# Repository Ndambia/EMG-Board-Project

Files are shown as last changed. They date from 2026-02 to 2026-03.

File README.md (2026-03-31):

# 3-Channel EMG Data Acquisition System (ESP32-Based)

## Overview

This project is a **3-channel Electromyography (EMG) Data Acquisition (DAQ) system** built around an **ESP32 MCU**. It is designed to acquire low-level biopotential signals from muscles, condition them using an analog front-end, digitize them via an external ADC, and transmit or store the data for further processing.

The system is modular and portable, integrating power management for battery operation, making it suitable for wearable and embedded biomedical applications.

---

## Key Features

* Three independent EMG input channels
* External multi-channel ADC with I²C interface
* ESP32 MCU for control, DSP, and communication
* Li-Po battery charging support
* Boost / regulation circuitry for stable operation
* Compact PCB designed for embedded and wearable use

---

## System Architecture

### Signal Chain Overview

```
Muscle Electrodes
      ↓
EMG Analog Front-End (DAQ)
      ↓
External ADC (3 Channels)
      ↓  I²C
ESP32 MCU
      ↓
USB / BLE / Wi-Fi 
```

---

## Functional Block Description

### 1. EMG DAQ (Analog Front-End)

* Three independent EMG channels
* Powered at **3.3 V**
* Outputs conditioned analog signals suitable for ADC input

**Typical functionality includes:**

* Instrumentation amplification
* High-pass filtering to remove motion artifacts
* Low-pass filtering to reduce high-frequency noise
* Optional 50/60 Hz notch filtering

---

### 2. Analog-to-Digital Converter (ADC)

* Powered at **3.3 V**
* Three analog input channels
* Digital interface: **I²C (SDA, SCL)**

The ADC digitizes the conditioned EMG signals for processing by the ESP32.

---

### 3. Microcontroller Unit (ESP32)

* Powered at **3.3 V**
* Configures and reads data from the ADC
* Performs optional digital signal processing (RMS, envelope extraction)
* Supports USB, BLE, and Wi-Fi communication

---

### 4. Power Management

#### Li-Po Battery Charger

* Supports single-cell Li-Po batteries
* USB-powered charging
* Enables portable operation

#### Boost / Regulation Circuit

* Maintains stable system voltage during battery discharge
* Ensures reliable operation of analog and digital blocks

---

## PCB Design

### PCB Back Layer

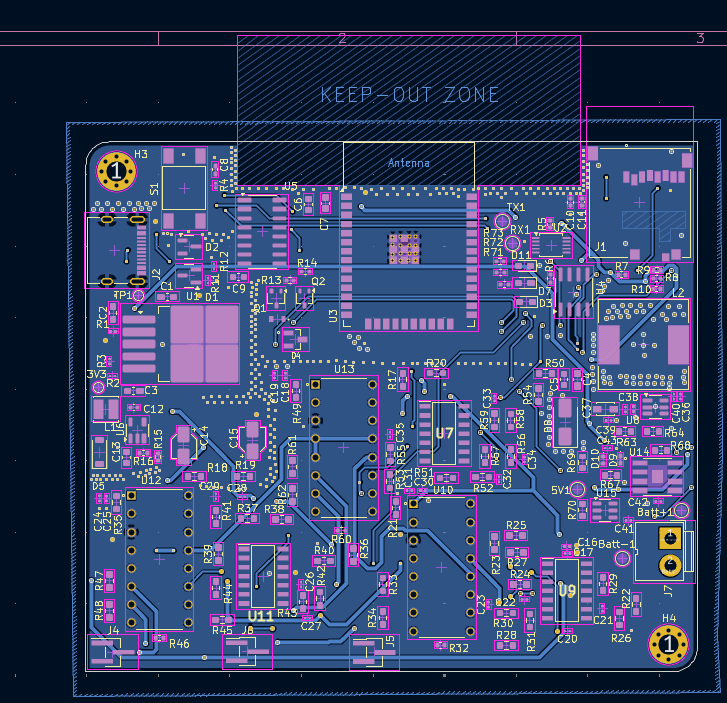
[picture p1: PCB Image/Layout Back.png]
PCB Back

The back layer shows the ground plane distribution and return paths. Care was taken to maintain a low-impedance ground for the analog EMG front-end to minimize noise coupling from digital sections.

### PCB Front Layer

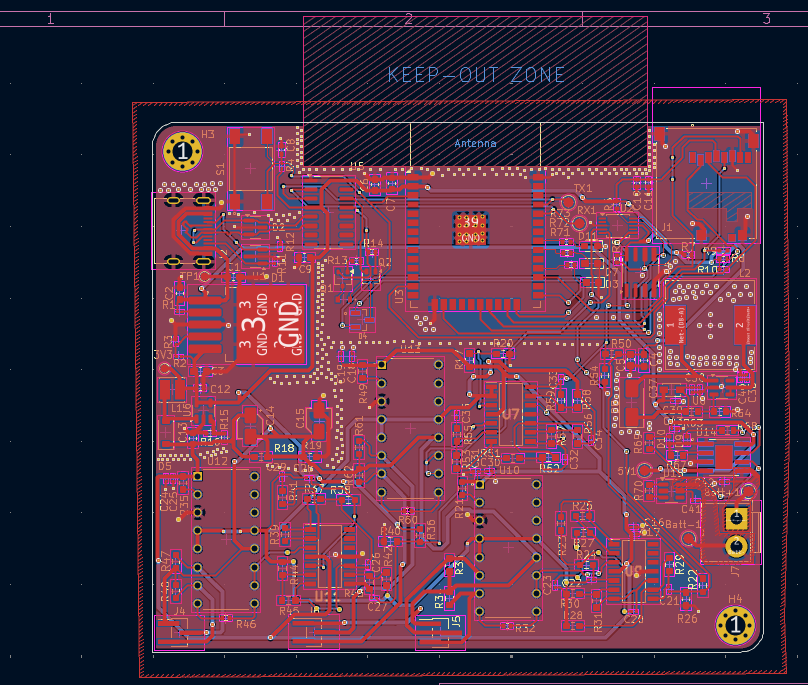
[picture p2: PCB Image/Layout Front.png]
PCB Front

The front layer contains the majority of signal routing and component placement. Analog EMG paths are kept short and isolated from high-speed digital and power traces.

### PCB Routing Overview

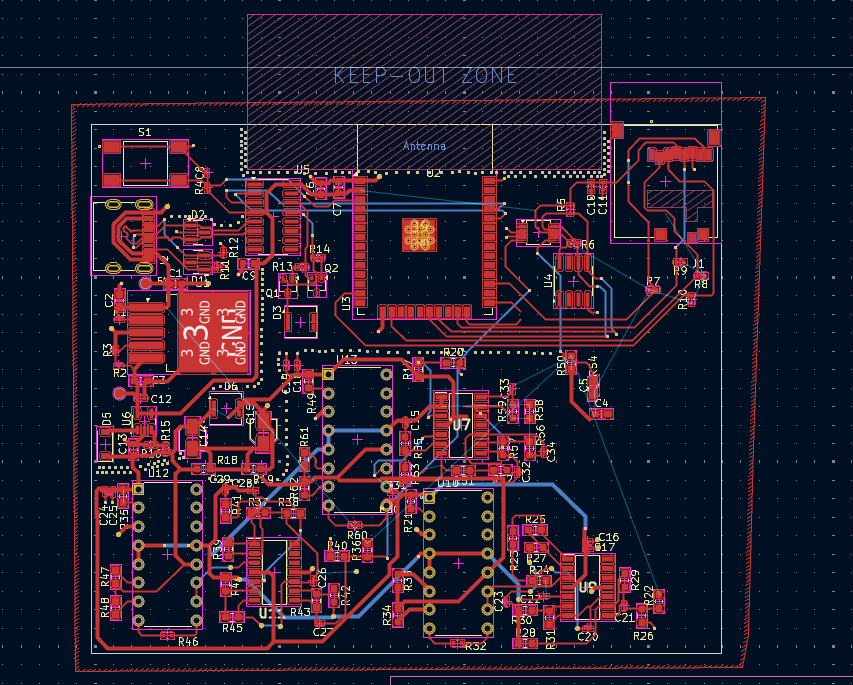
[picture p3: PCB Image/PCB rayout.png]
PCB Layout

This image provides an overall routing overview, highlighting trace organization, separation between analog and digital domains, and controlled routing for sensitive EMG signals.

### Routing – Front

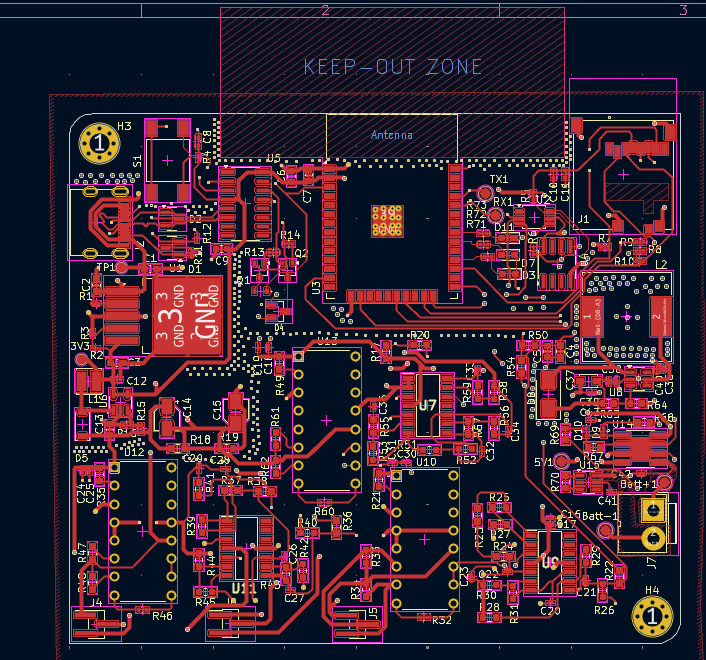
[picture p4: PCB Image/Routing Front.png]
Routing Front

The front routing layer illustrates how EMG signal traces are carefully routed with minimal vias to reduce interference and preserve signal integrity.

### Routing – Back

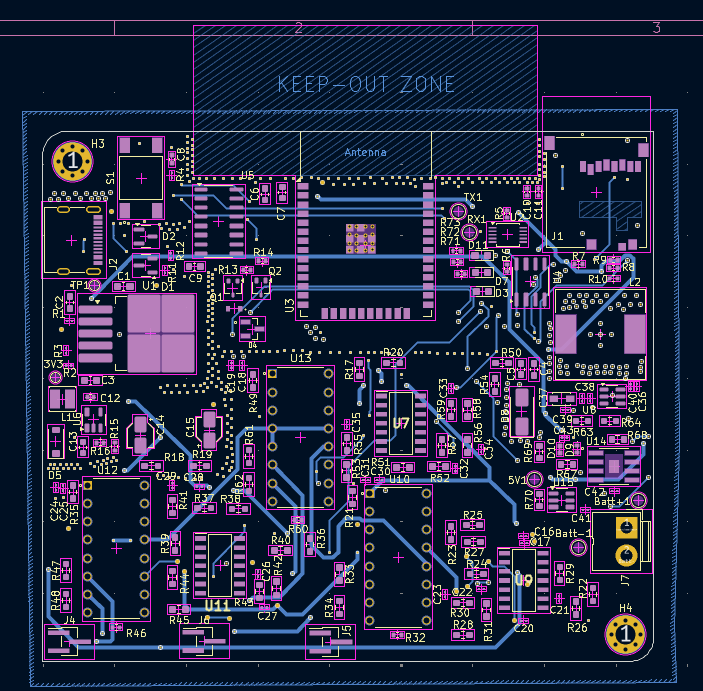
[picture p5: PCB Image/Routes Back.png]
Routing Back

Back-side routing is primarily used for ground returns and power distribution, helping to maintain clean reference planes for low-noise acquisition.

### PCB 3D View

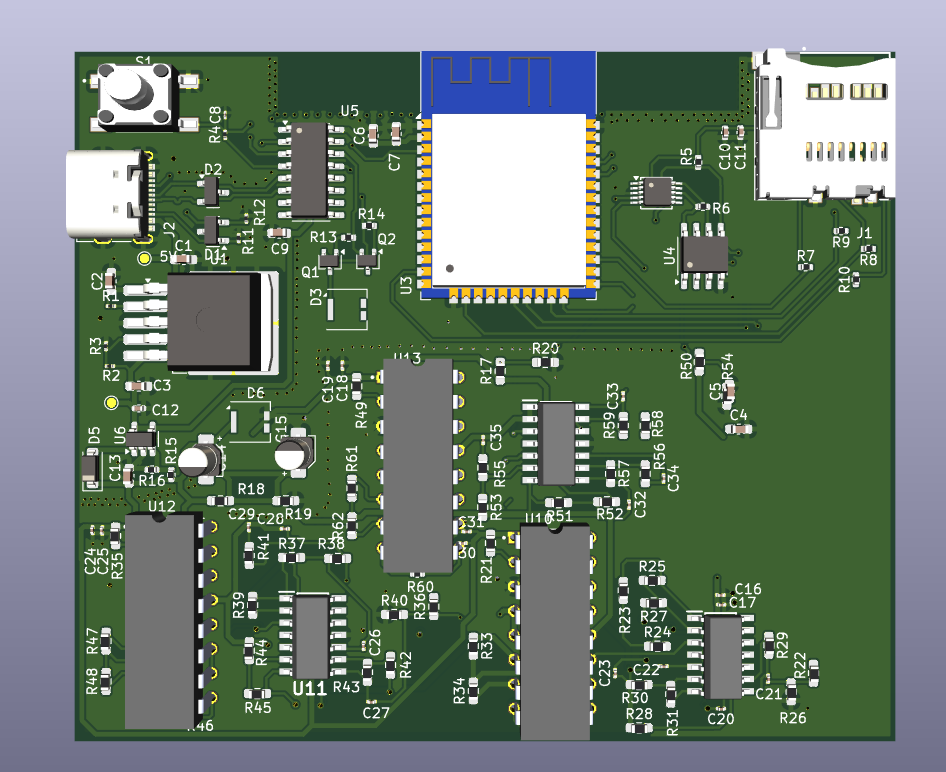
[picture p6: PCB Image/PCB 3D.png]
PCB 3D

The 3D view shows overall board dimensions, component height clearance, and suitability for enclosure or wearable integration.

### PCB Front 3D View

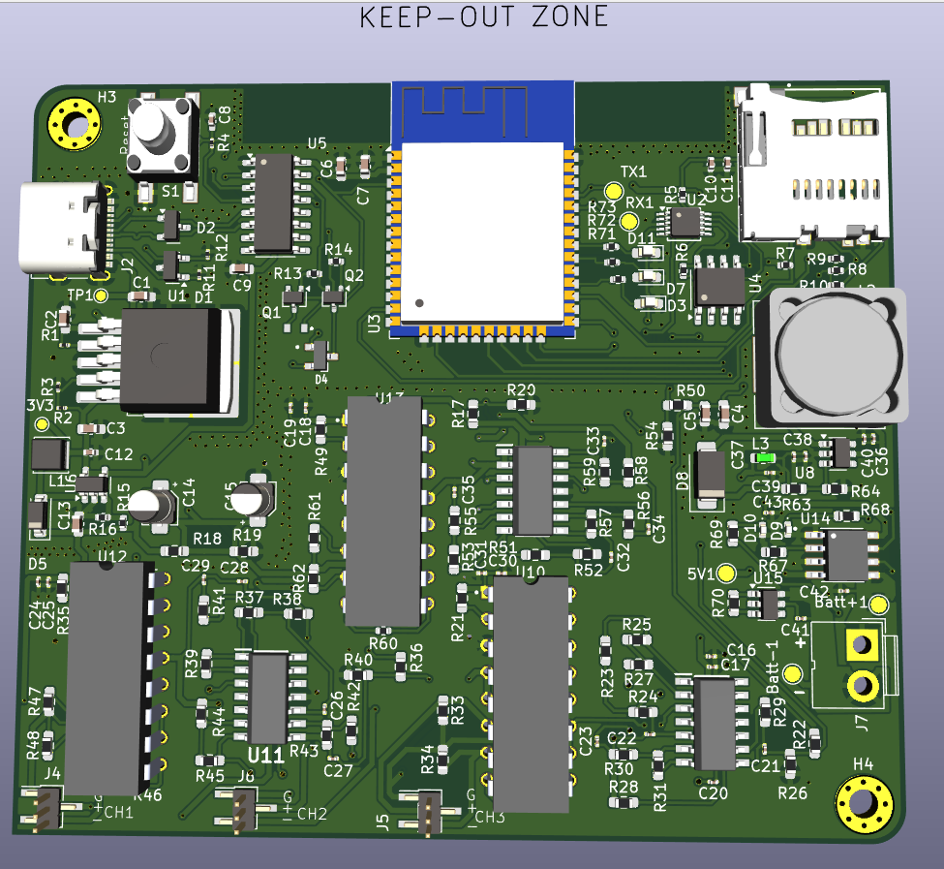
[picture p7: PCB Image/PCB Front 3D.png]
PCB Front 3D

This view highlights top-side component placement, including the ESP32 module, ADC, and EMG front-end circuitry.

### PCB Back 3D View

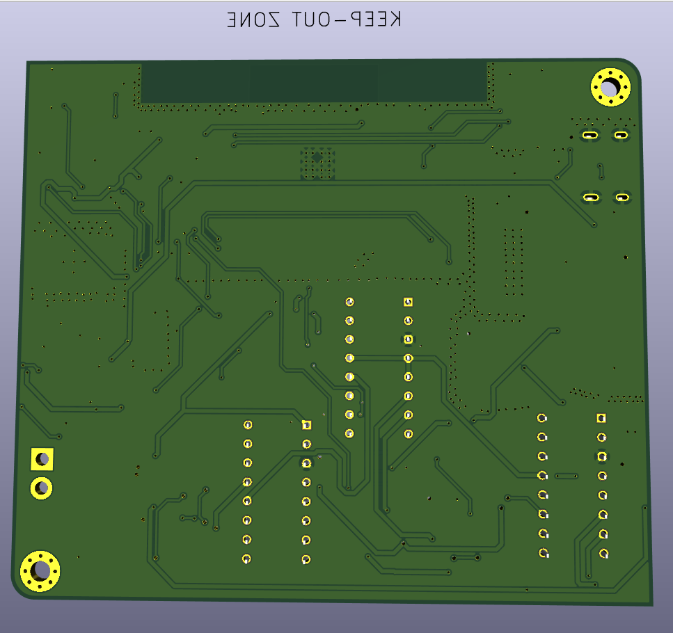
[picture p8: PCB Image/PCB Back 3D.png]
PCB Back 3D

The back-side 3D view shows passive components, ground stitching vias, and mechanical layout considerations.

### Design Progress Snapshot

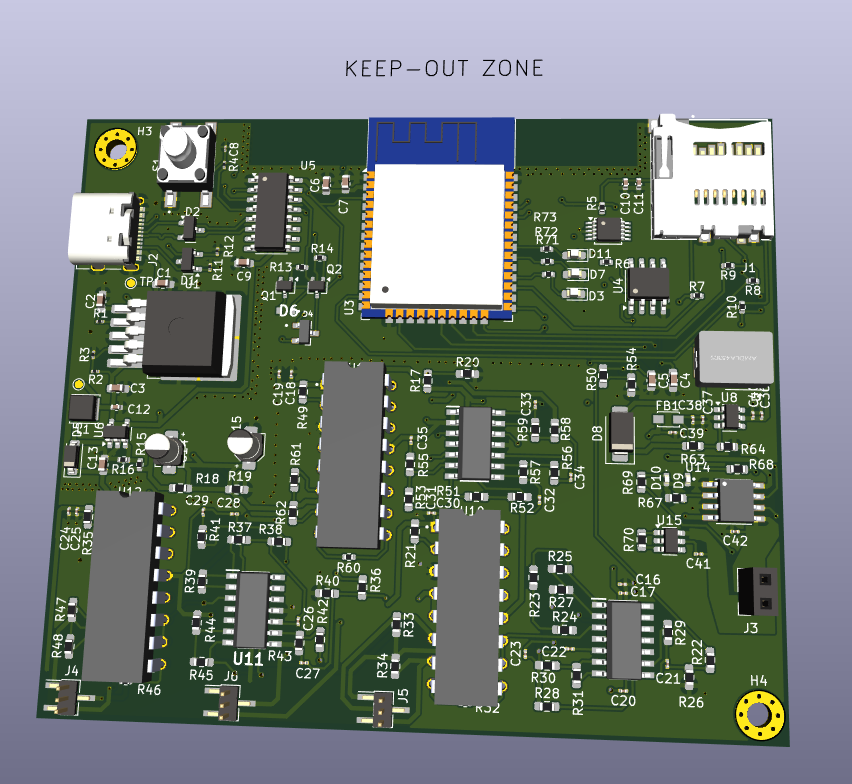
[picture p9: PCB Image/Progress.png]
Progress

This image documents the PCB design progress during layout and routing stages.

### Schematics

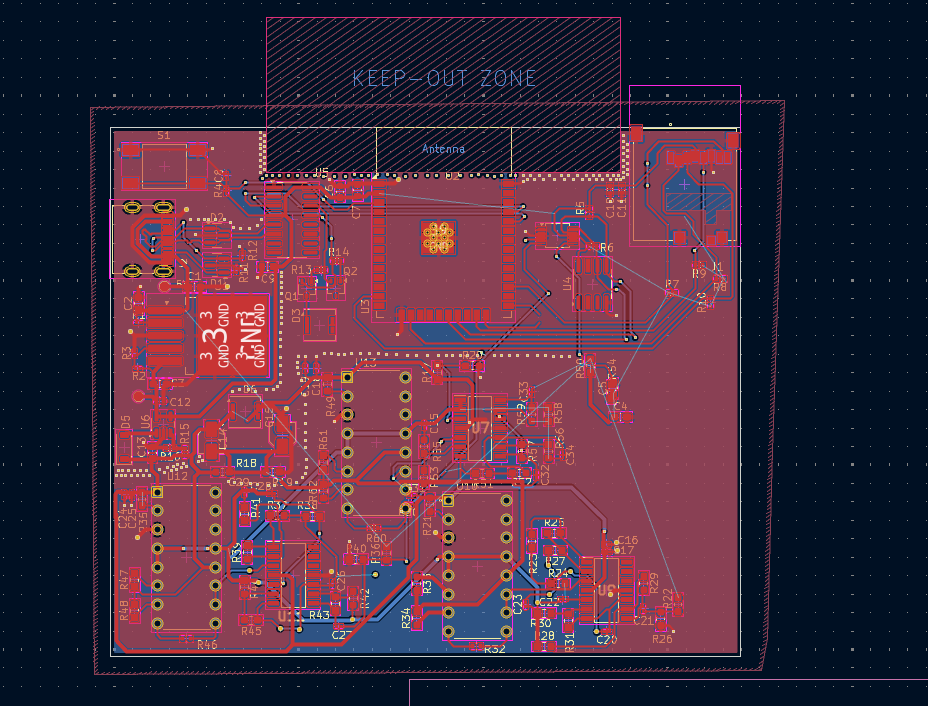
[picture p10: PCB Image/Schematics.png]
Schematics

The schematic captures the complete system design, including EMG analog front-end, ADC, ESP32 MCU, and power management circuitry.

---

## Intended Applications

* Multi-channel EMG signal acquisition
* Wearable biomedical research devices
* Prosthetics and rehabilitation research
* Gesture recognition and HMI systems
* Academic and laboratory EMG experimentation

---

## Design Notes & Safety

* Proper analog grounding and shielding are critical for low-noise EMG acquisition
* Use shielded electrode cables where possible
* This system is intended for **research and educational use only**
* Not certified for clinical or diagnostic applications

---

## Author

**Eng. Ndambia M.**
MyGen Solutions

---

## License & Disclaimer

This project is provided for **research and educational purposes only**. It is not a certified medical device and must not be used for clinical diagnosis or treatment.

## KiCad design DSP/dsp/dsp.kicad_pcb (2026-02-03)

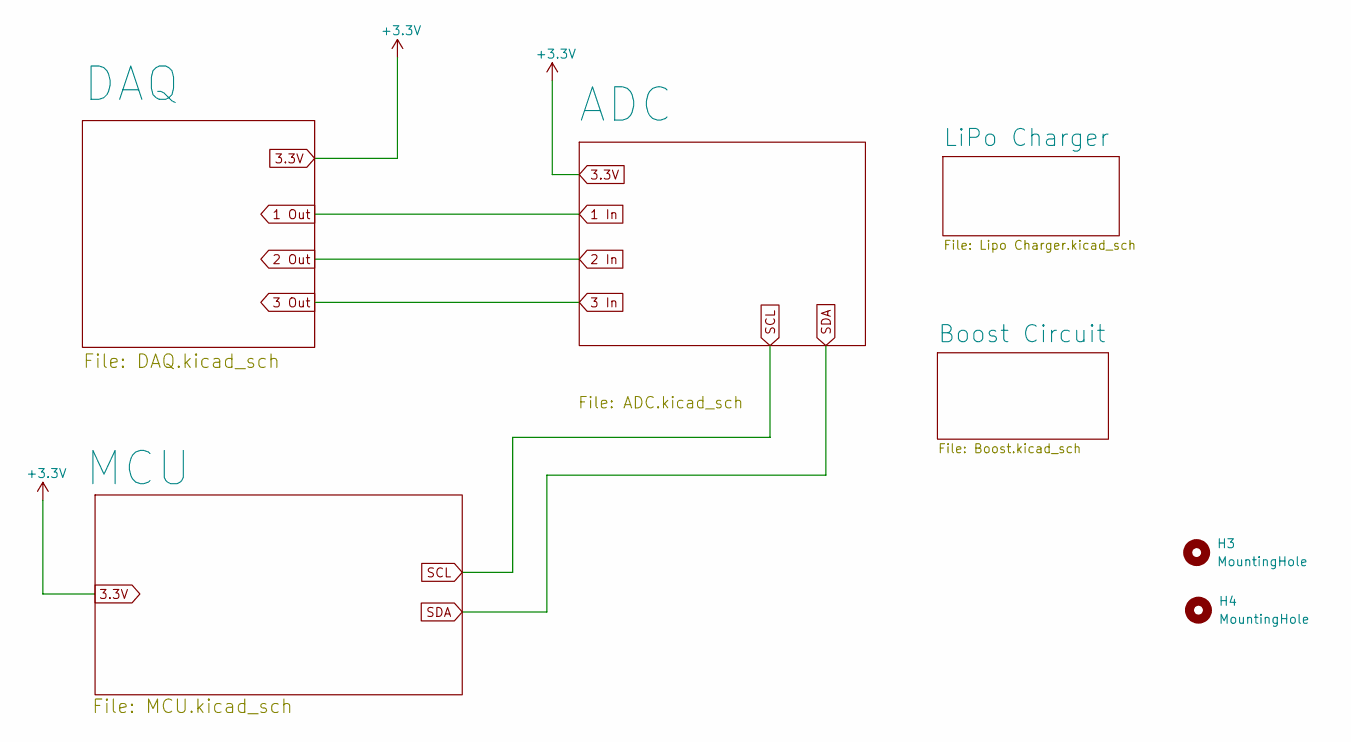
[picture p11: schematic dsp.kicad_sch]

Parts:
H3, H4: MountingHole; MountingHole_2.7mm_M2.5_Pad_Via

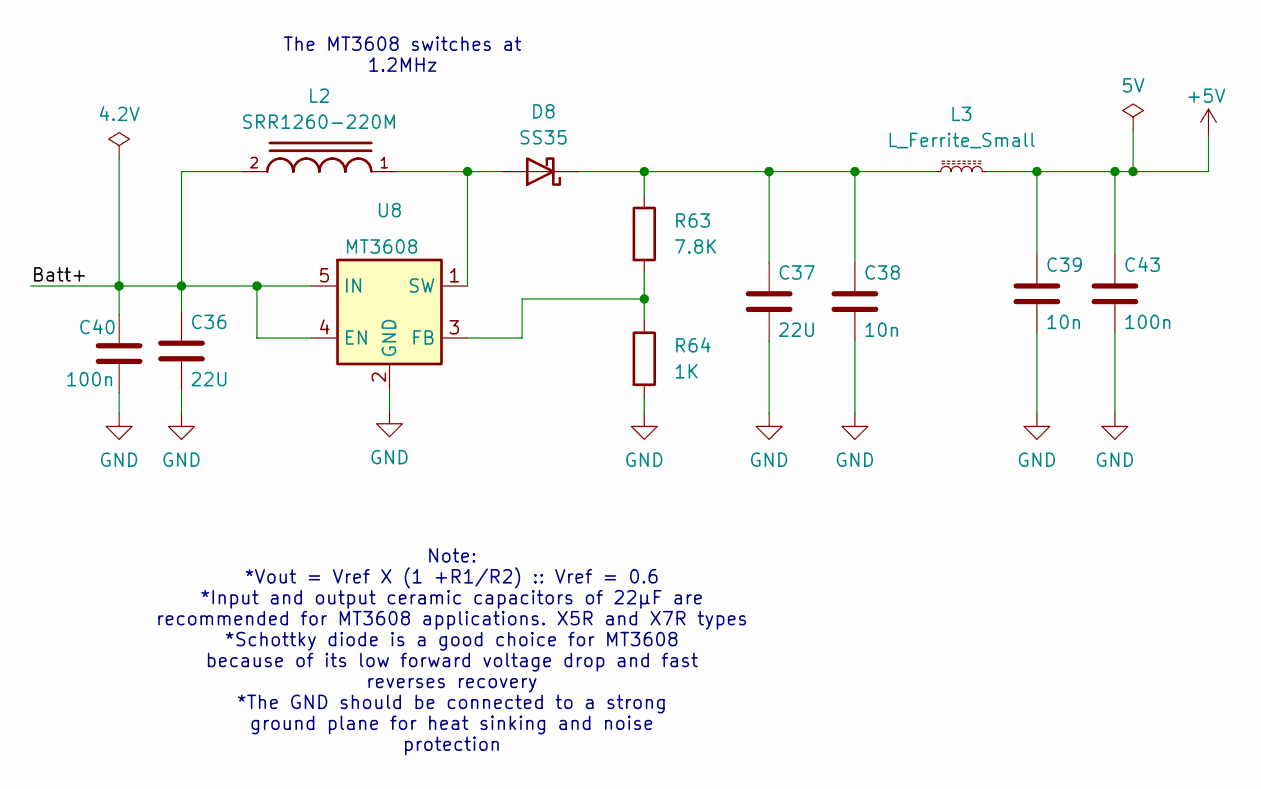
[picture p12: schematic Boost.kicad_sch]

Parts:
C36, C37: 22U; C_0201_0603Metric
C38, C39: 10n; C_0201_0603Metric
C40, C43: 100n; C_0201_0603Metric
D8: SS35; D_SMA
L2: SRR1260-220M; INDP125125X600N
L3: L_Ferrite_Small; L_0603_1608Metric
R63: 7.8K; R_0603_1608Metric
R64: 1K; R_0603_1608Metric
U8: MT3608; SOT-23-6

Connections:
5V: C39.1, C43.1, L3.2; also elsewhere on the board
/Boost Circuit/Batt+: C36.1, C40.1, L2.2, U8.4 (EN), U8.5 (IN)
GND: C36.2, C37.2, C38.2, C39.2, C40.2, C43.2, R64.2, U8.2 (GND); also elsewhere on the board
unnamed: D8.2 (A), L2.1, U8.1 (SW)
unnamed: C37.1, C38.1, D8.1 (K), L3.1, R63.1
unnamed: R63.2, R64.1, U8.3 (FB)

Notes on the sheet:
Note: *Vout = Vref X (1 +R1/R2) :: Vref = 0.6 *Input and output ceramic capacitors of 22μF are recommended for MT3608 applications. X5R and X7R types *Schottky diode is a good choice for MT3608 because of its low forward voltage drop and fast reverses recovery *The GND should be connected to a stro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
The MT3608 switches at 1.2MHz

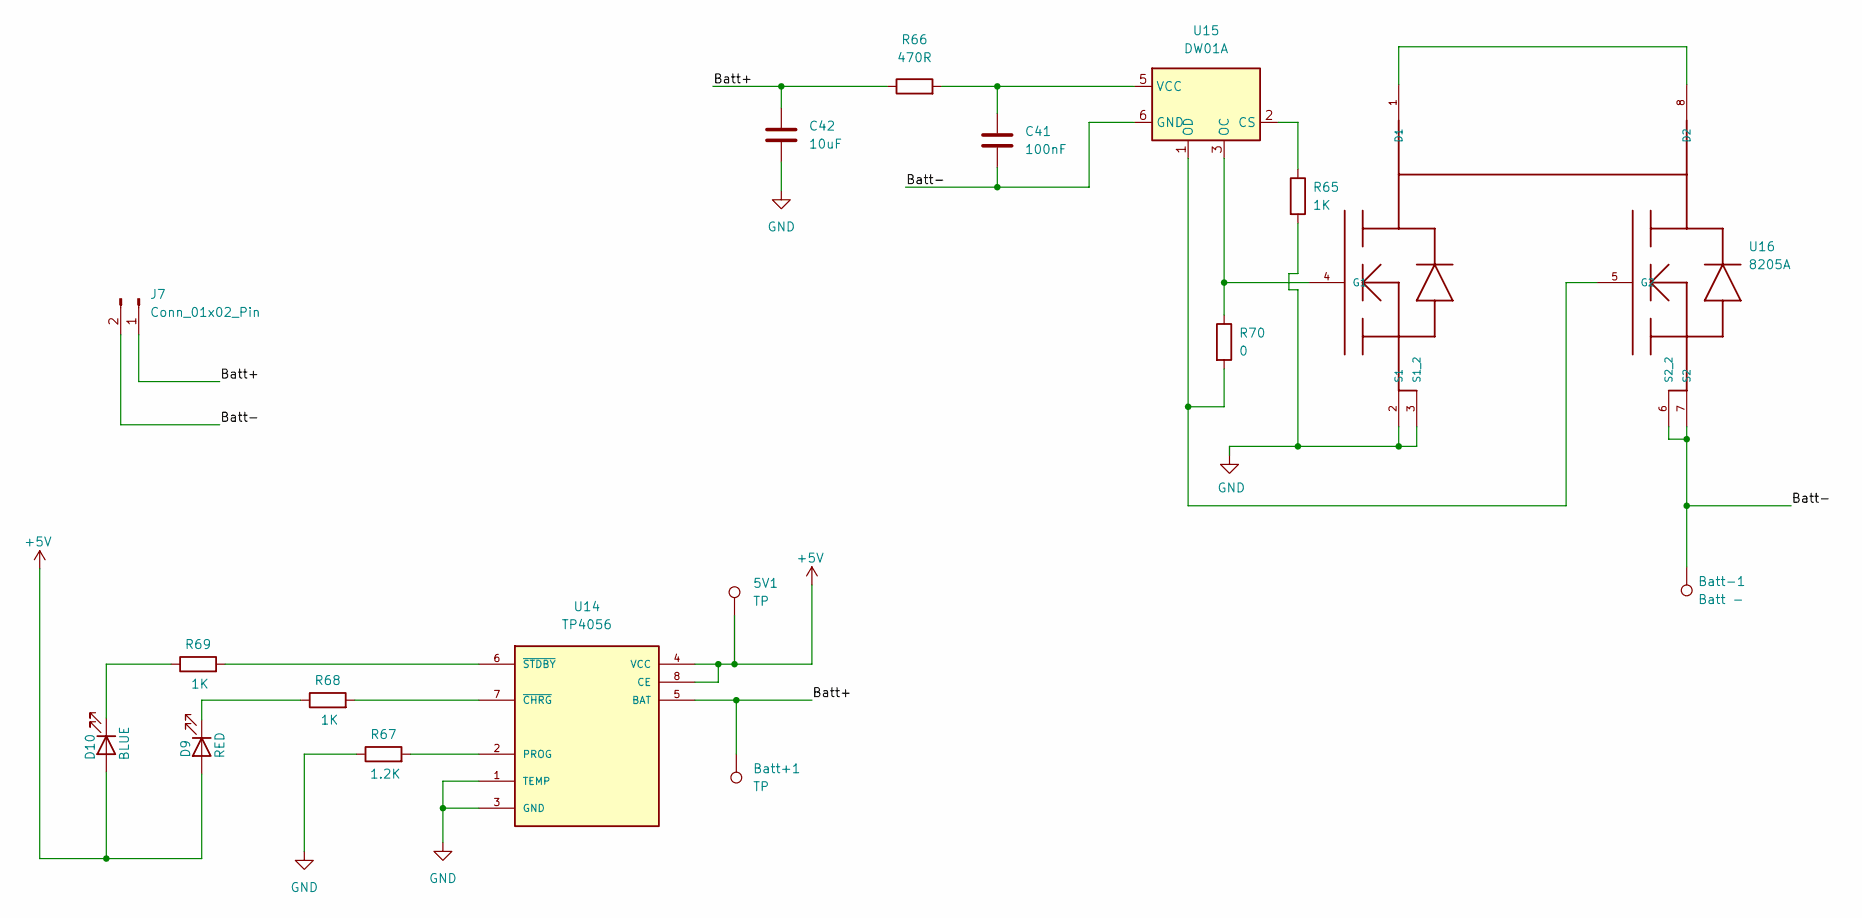
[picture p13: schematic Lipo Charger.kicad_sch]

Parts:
5V1: TP; TestPoint_Pad_D1.5mm
Batt+1: TP; TestPoint_Pad_D1.5mm
Batt-1: Batt -; TestPoint_Pad_D1.5mm
C41: 100nF; C_0201_0603Metric
C42: 10uF; C_0201_0603Metric
D9: RED; LED_0402_1005Metric
D10: BLUE; LED_0402_1005Metric
J7: Conn_01x02_Pin; JWT_A3963_1x02_P3.96mm_Vertical
R65, R68, R69: 1K; R_0603_1608Metric
R66: 470R; R_0603_1608Metric
R67: 1.2K; R_0603_1608Metric
R70: 0; R_0603_1608Metric
U14: TP4056; SOP127P600X175-9N
U15: DW01A; SOT-23-6
U16: 8205A; TSSOP8

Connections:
5V: 5V1.1, D9.2 (A), D10.2 (A), U14.4 (VCC), U14.8 (CE); also elsewhere on the board
/LiPo Charger/Batt+: Batt+1.1, C42.1, J7.1, R66.1, U14.5 (BAT)
/LiPo Charger/Batt-: Batt-1.1, C41.2, J7.2, U15.6 (GND), U16.6 (S2_2), U16.7 (S2)
GND: C42.2, R65.2, R67.1, U14.1 (TEMP), U14.3 (GND), U16.2 (S1), U16.3 (S1_2); also elsewhere on the board
unnamed: D9.1 (K), R68.1
unnamed: D10.1 (K), R69.1
unnamed: R67.2, U14.2 (PROG)
unnamed: R68.2, U14.7 (~CHRG)
unnamed: R69.2, U14.6 (~STDBY)
unnamed: R65.1, U15.2 (CS)
unnamed: R70.1, U15.3 (OC), U16.4 (G1)
unnamed: R70.2, U15.1 (OD), U16.5 (G2)
unnamed: C41.1, R66.2, U15.5 (VCC)
unnamed: U16.1 (D1), U16.8 (D2)

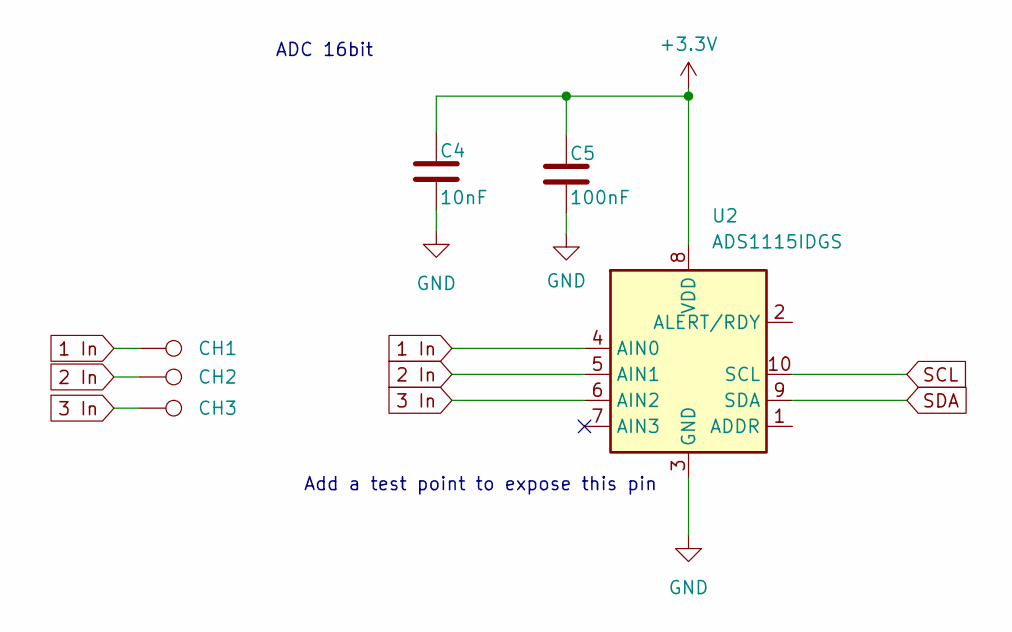
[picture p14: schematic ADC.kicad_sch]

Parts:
C4: 10nF; C_0603_1608Metric_Pad1.08x0.95mm_HandSolder
C5: 100nF; C_0603_1608Metric
CH1: 1; TestPoint_Pad_D1.0mm
CH2: 2; TestPoint_Pad_D1.0mm
CH3: 23; TestPoint_Pad_D1.0mm
U2: ADS1115IDGS; TSSOP-10_3x3mm_P0.5mm

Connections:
3.3V: C4.1, C5.1, U2.8 (VDD); also elsewhere on the board
GND: C4.2, C5.2, U2.3 (GND); also elsewhere on the board
SCL: U2.10 (SCL); also elsewhere on the board
SDA: U2.9 (SDA); also elsewhere on the board

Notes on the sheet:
ADC 16bit
Add a test point to expose this pin

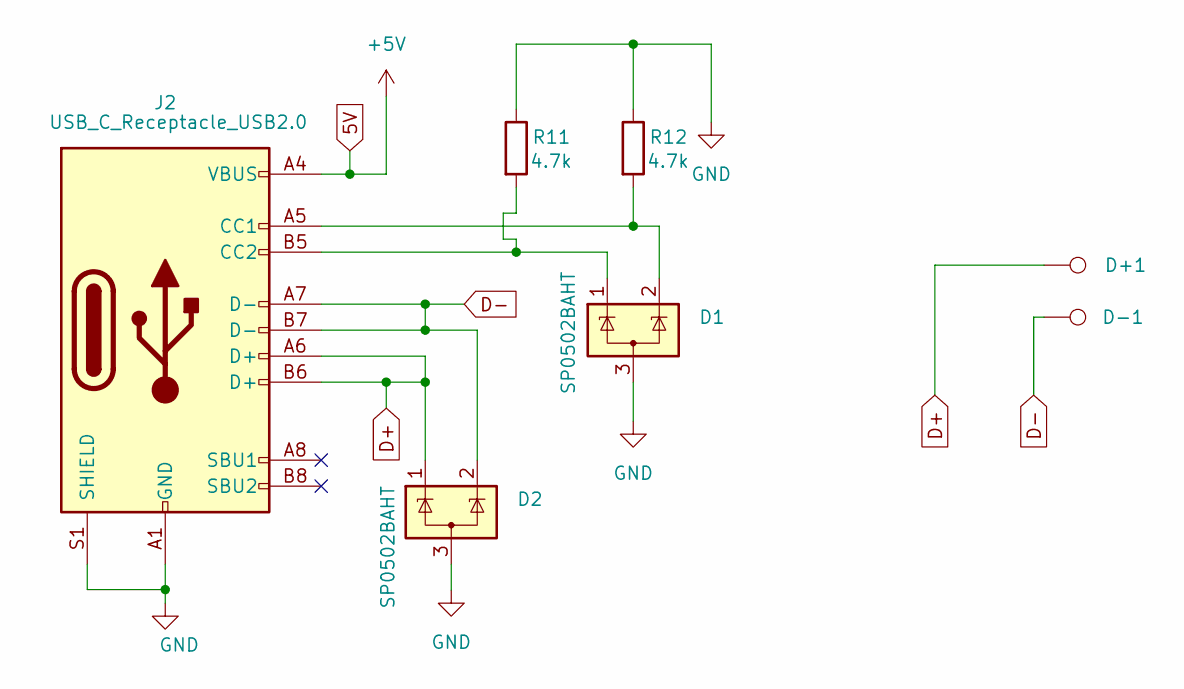
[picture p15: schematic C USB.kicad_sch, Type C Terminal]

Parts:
D1, D2: SP0502BAHT; SOT-23
D+1: D+; TestPoint_Pad_D1.0mm
D-1: D-; TestPoint_Pad_D1.0mm
J2: USB_C_Receptacle_USB2.0; USB_C_Receptacle_G-Switch_GT-USB-7010ASV
R11, R12: 4.7k; R_0201_0603Metric

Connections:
5V: J2.A4 (VBUS), J2.A9 (VBUS), J2.B4 (VBUS), J2.B9 (VBUS); also elsewhere on the board
D+: D2.1 (K), D+1.1, J2.A6 (D+), J2.B6 (D+); also elsewhere on the board
D-: D2.2 (K), D-1.1, J2.A7 (D-), J2.B7 (D-); also elsewhere on the board
GND: D1.3 (A), D2.3 (A), J2.A1 (GND), J2.A12 (GND), J2.B1 (GND), J2.B12 (GND), J2.S1 (SHIELD), R11.1, R12.1; also elsewhere on the board
unnamed: D1.2 (K), J2.A5 (CC1), R12.2
unnamed: D1.1 (K), J2.B5 (CC2), R11.2

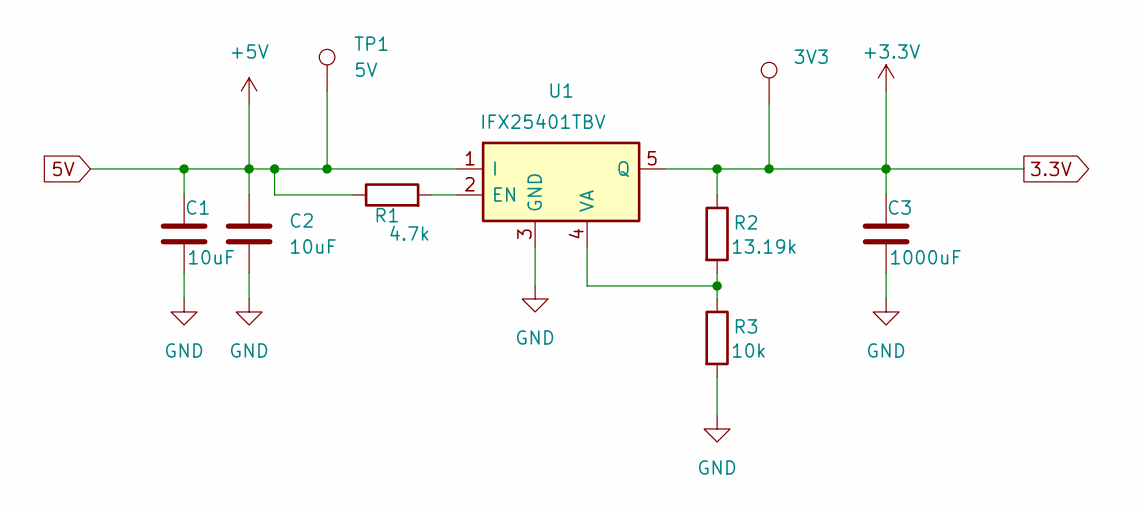
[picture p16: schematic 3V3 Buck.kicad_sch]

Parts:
3V3: TestPoint_Pad_D1.0mm
C1, C2: 10uF; C_0603_1608Metric_Pad1.08x0.95mm_HandSolder
C3: 1000uF; C_0603_1608Metric_Pad1.08x0.95mm_HandSolder
R1: 4.7k; R_0201_0603Metric
R2: 13.19k; R_0201_0603Metric
R3: 10k; R_0201_0603Metric
TP1: 5V; TestPoint_Pad_D1.0mm
U1: IFX25401TBV; TO-263-5_TabPin3

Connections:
3.3V: 3V3.1, C3.1, R2.1, U1.5 (Q); also elsewhere on the board
5V: C1.1, C2.1, R1.1, TP1.1, U1.1 (I); also elsewhere on the board
GND: C1.2, C2.2, C3.2, R3.2, U1.3 (GND); also elsewhere on the board
unnamed: R1.2, U1.2 (EN)
unnamed: R2.2, R3.1, U1.4 (VA)

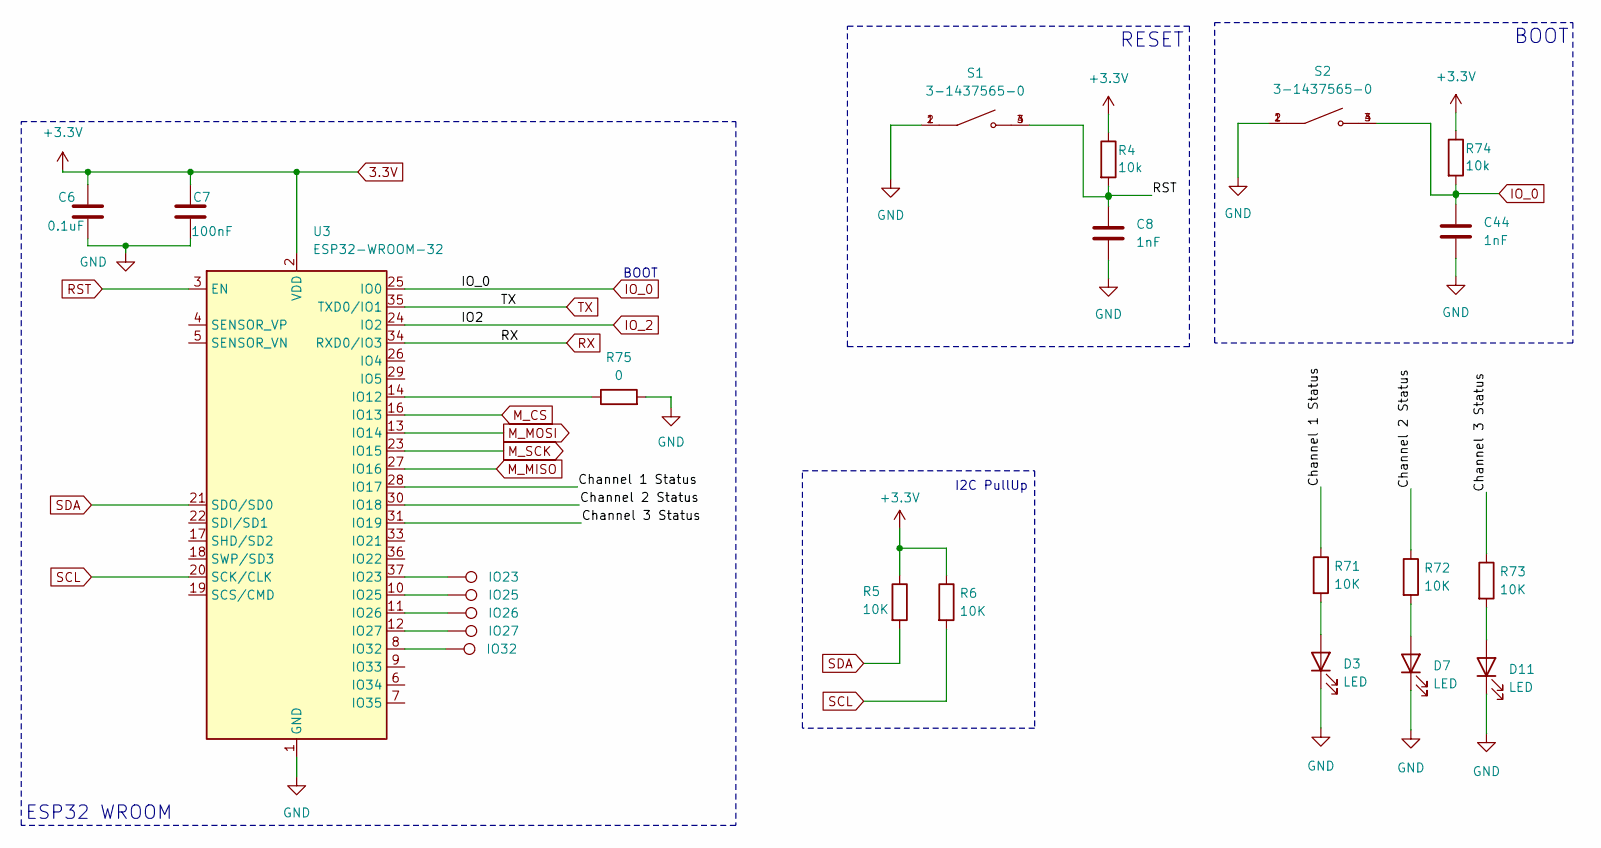
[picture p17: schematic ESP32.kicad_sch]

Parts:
C6: 0.1uF; C_0603_1608Metric
C7: 100nF; C_0603_1608Metric
C8, C44: 1nF; C_0402_1005Metric_Pad0.74x0.62mm_HandSolder
D3, D7, D11: LED; LED_0603_1608Metric_Pad1.05x0.95mm_HandSolder
IO23: 23; TestPoint_Pad_D1.0mm
IO25: 25; TestPoint_Pad_D1.0mm
IO26: 26; TestPoint_Pad_D1.0mm
IO27: 27; TestPoint_Pad_D1.0mm
IO32: 32; TestPoint_Pad_D1.0mm
R4, R74: 10k; R_0201_0603Metric
R5, R6, R71, R72, R73: 10K; R_0402_1005Metric
R75: 0; R_0402_1005Metric
S1, S2: 3-1437565-0; SW_3-1437565-0; PARTREV V
U3: ESP32-WROOM-32

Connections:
3.3V: C6.1, C7.1, R4.1, R5.1, R6.1, R74.1, U3.2 (VDD); also elsewhere on the board
/MCU/ESP32 Wroom/Channel 1 Status: R71.1, U3.28 (IO17)
/MCU/ESP32 Wroom/Channel 2 Status: R72.1, U3.30 (IO18)
/MCU/ESP32 Wroom/Channel 3 Status: R73.1, U3.31 (IO19)
GND: C6.2, C7.2, C8.2, C44.2, D3.1 (K), D7.1 (K), D11.1 (K), R75.2, S1.1, S1.2, S2.1, S2.2, U3.1 (GND), U3.15 (GND), U3.38 (GND), U3.39 (GND); also elsewhere on the board
IO_0: C44.1, R74.2, S2.3, S2.4, U3.25 (IO0); also elsewhere on the board
IO_2: U3.24 (IO2); also elsewhere on the board
M_CS: U3.16 (IO13); also elsewhere on the board
M_MISO: U3.27 (IO16); also elsewhere on the board
M_MOSI: U3.13 (IO14); also elsewhere on the board
M_SCK: U3.23 (IO15); also elsewhere on the board
unnamed: D3.2 (A), R71.2
unnamed: D7.2 (A), R72.2
unnamed: D11.2 (A), R73.2
unnamed: R75.1, U3.14 (IO12)
unnamed: IO23.1, U3.37 (IO23)
unnamed: IO25.1, U3.10 (IO25)
unnamed: IO26.1, U3.11 (IO26)
unnamed: IO27.1, U3.12 (IO27)
unnamed: IO32.1, U3.8 (IO32)
RST: C8.1, R4.2, S1.3, S1.4, U3.3 (EN); also elsewhere on the board
RX: U3.34 (RXD0/IO3); also elsewhere on the board
SCL: R6.2, U3.20 (SCK/CLK); also elsewhere on the board
SDA: R5.2, U3.21 (SDO/SD0); also elsewhere on the board
TX: U3.35 (TXD0/IO1); also elsewhere on the board

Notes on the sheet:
BOOT
RESET
ESP32 WROOM
BOOT
I2C PullUp

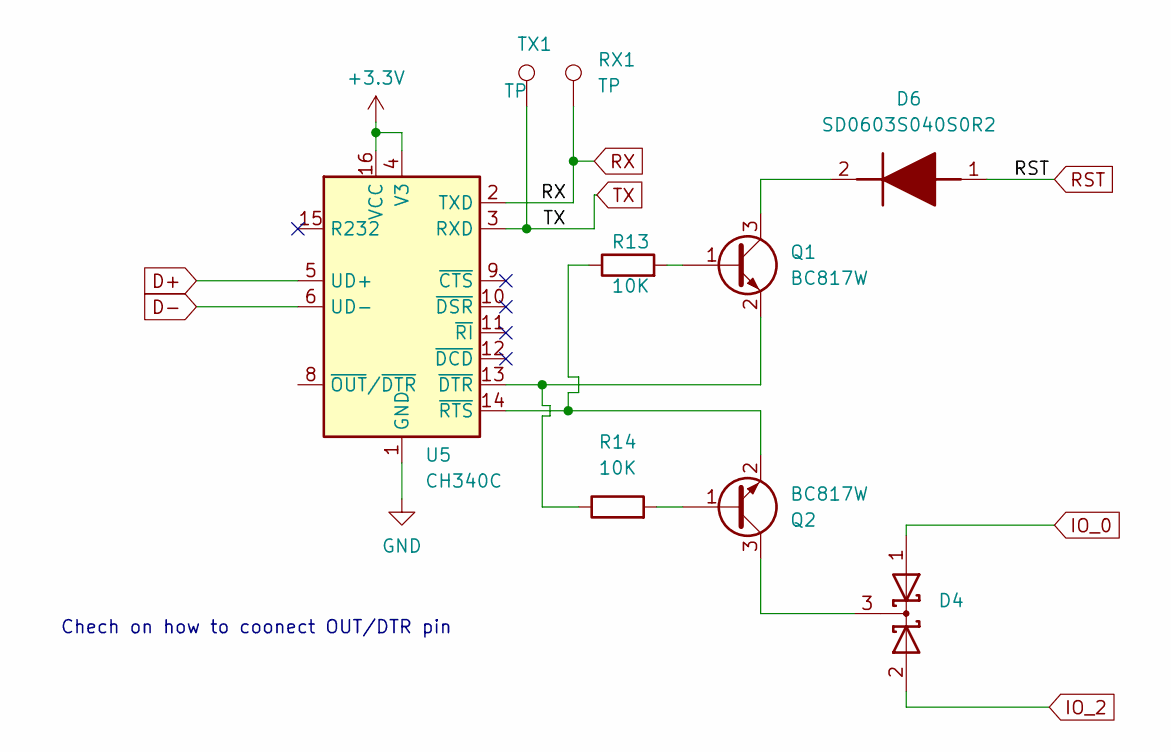
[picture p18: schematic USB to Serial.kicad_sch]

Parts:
D4: D_Schottky_Dual_CommonCathode_AAK; SOT95P230X110-3N
D6: SD0603S040S0R2; SD0603; Manufacturer_Part_Number SD0603S040S0R2; Mouser Part Number 581-SD0603S040S0R2
Q1, Q2: BC817W; SOT-323_SC-70
R13, R14: 10K; R_0402_1005Metric
RX1: TP; TestPoint_Pad_D1.5mm
TX1: TP; TestPoint_Pad_D1.5mm
U5: CH340C; SOIC-16_3.9x9.9mm_P1.27mm

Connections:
3.3V: U5.4 (V3), U5.16 (VCC); also elsewhere on the board
D+: U5.5 (UD+); also elsewhere on the board
D-: U5.6 (UD-); also elsewhere on the board
GND: U5.1 (GND); also elsewhere on the board
IO_0: D4.1 (A); also elsewhere on the board
IO_2: D4.2 (A); also elsewhere on the board
unnamed: D4.3 (K), Q2.3 (C)
unnamed: D6.2 (K), Q1.3 (C)
unnamed: Q1.1 (B), R13.2
unnamed: Q1.2 (E), R14.1, U5.13 (~DTR)
unnamed: Q2.1 (B), R14.2
unnamed: Q2.2 (E), R13.1, U5.14 (~RTS)
RST: D6.1 (A); also elsewhere on the board
RX: RX1.1, U5.2 (TXD); also elsewhere on the board
TX: TX1.1, U5.3 (RXD); also elsewhere on the board

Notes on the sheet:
Chech on how to coonect OUT/DTR pin

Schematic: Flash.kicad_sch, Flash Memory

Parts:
C9: 100nF; C_0603_1608Metric
U4: AT24CS64-SSHM; SOIC-8_3.9x4.9mm_P1.27mm

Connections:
3.3V: C9.2, U4.8 (VCC); also elsewhere on the board
GND: C9.1, U4.4 (GND); also elsewhere on the board
SCL: U4.6 (SCL); also elsewhere on the board
SDA: U4.5 (SDA); also elsewhere on the board

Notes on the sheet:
EEEPROM

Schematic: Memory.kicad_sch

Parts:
C10: 1u; C_0402_1005Metric
C11: 0.01u; C_0402_1005Metric
J1: MEM2052-00-195-00-A_REVA; GCT_MEM2052-00-195-00-A_REVA; PARTREV A
R7, R8, R9, R10: 10k; R_0402_1005Metric

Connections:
3.3V: C10.1, C11.1, J1.P4 (VDD), R7.1, R8.1, R9.1, R10.1; also elsewhere on the board
GND: C10.2, C11.2, J1.G1 (SHIELD_GND), J1.G2 (SHIELD_GND), J1.G3 (SHIELD_GND), J1.G4 (SHIELD_GND), J1.P6 (VSS); also elsewhere on the board
M_CS: J1.P2 (CD/DAT3), R8.2; also elsewhere on the board
M_MISO: J1.P7 (DAT0), R7.2; also elsewhere on the board
M_MOSI: J1.P3 (CMD), R10.2; also elsewhere on the board
M_SCK: J1.P5 (CLK), R9.2; also elsewhere on the board

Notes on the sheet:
SPI PULLUP RESISTORS

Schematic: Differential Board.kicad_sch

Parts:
C16, C17, C19, C25, C31: 0.1uF; C_0201_0603Metric
C18, C21, C23, C24, C27, C29, C30, C33, C35: 10nF; C_0201_0603Metric
C20, C26, C32: 240nF; C_0201_0603Metric
C22, C28, C34: 120nF; C_0201_0603Metric
ELEC1+1, ELEC1-1, ELEC2+1, ELEC2-1, ELEC3+1, ELEC3-1: 2; TestPoint_Pad_D1.0mm
FGND1: 2; TestPoint_Pad_D1.0mm
FIL1, FIL2, FIL3: 2; TestPoint_Pad_D1.0mm
J4, J5, J6: Conn_01x03_Pin; PinHeader_1x03_P1.27mm_Vertical_SMD_Pin1Left
R21, R22, R26, R27, R31, R33, R34, R35, R36, R40, R41, R45, R47, R48, R49, R50, R54, R55, R57, R59, R61, R62: 10k; R_0603_1608Metric_Pad0.98x0.95mm_HandSolder
R23, R37, R51: 2.2K; R_0603_1608Metric_Pad0.98x0.95mm_HandSolder
R24, R38, R52: 2.2k; R_0603_1608Metric_Pad0.98x0.95mm_HandSolder
R25, R28, R29, R30, R39, R42, R43, R44, R53, R56, R58: 1k; R_0603_1608Metric_Pad0.98x0.95mm_HandSolder
R32, R46, R60: 470; R_0402_1005Metric
RAW1, RAW2, RAW3: 1; TestPoint_Pad_D1.0mm
REF_GND1: 2; TestPoint_Pad_D1.0mm
U7, U9, U11: LM324A; SOIC127P600X175-14N
U10, U12, U13: INA125P; DIP794W45P254L1969H508Q16

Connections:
3.3V: R22.2, R36.2, R50.2; also elsewhere on the board
12V: C16.1, C17.1, C18.1, C19.1, C24.1, C25.1, C30.1, C31.1, R21.1, R35.1, R49.1, U7.4 (V+), U9.4 (V+), U10.1 (V+), U11.4 (V+), U12.1 (V+), U13.1 (V+); also elsewhere on the board
+ Electrode: ELEC1+1.1, J5.2, R33.1, U10.6 (V+IN)
+ Electrode 2: ELEC2-1.1, J4.2, R47.1, U12.6 (V+IN)
+ Electrode 3: ELEC3+1.1, J6.2, R61.1, U13.6 (V+IN)
- Electrode: ELEC1-1.1, J5.3, R34.1, U10.7 (V-IN)
- Electrode 2: ELEC2+1.1, J4.3, R48.1, U12.7 (V-IN)
- Electrode 3: ELEC3-1.1, J6.3, R62.1, U13.7 (V-IN)
Float GND: FGND1.1, J4.1, J5.1, J6.1, R33.2, R34.2, R47.2, R48.2, R61.2, R62.2, REF_GND1.1, U10.12 (VREFCOM), U12.12 (VREFCOM), U13.12 (VREFCOM); also elsewhere on the board
Float GND 2: C22.2, C23.1, C28.2, C29.2, C34.2, C35.2, R28.1, R30.1, R42.1, R44.1, R56.1, R58.1, U10.4 (VREFOUT), U10.5 (IAREF), U10.13 (VREFBG), U12.4 (VREFOUT), U12.5 (IAREF), U12.13 (VREFBG), U13.4 (VREFOUT), U13.5 (IAREF), U13.13 (VREFBG); also elsewhere on the board
GND: C16.2, C17.2, C18.2, C19.2, C24.2, C25.2, C30.2, C31.2, R26.1, R40.1, R54.1, U7.11 (V-), U9.11 (V-), U10.3 (V-), U11.11 (V-), U12.3 (V-), U13.3 (V-); also elsewhere on the board
unnamed: C20.1, R23.2, R24.1
unnamed: C21.1, R29.2, U9.8
unnamed: C23.2, R27.2
unnamed: C26.1, R37.2, R38.1
unnamed: C27.1, R43.2, U11.8
unnamed: C29.1, R41.2
unnamed: C32.1, R51.2, R52.1
unnamed: C33.1, R59.2, U7.14
unnamed: C35.1, R55.2
unnamed: R23.1, R25.2, U9.1
unnamed: R32.1, U10.8 (RG)
unnamed: R32.2, U10.9 (RG)
unnamed: R37.1, R39.2, U11.1
unnamed: R46.1, U12.8 (RG)
unnamed: R46.2, U12.9 (RG)
unnamed: R51.1, R53.2, U7.7
unnamed: R60.1, U13.8 (RG)
unnamed: R60.2, U13.9 (RG)
unnamed: R53.1, R55.1, U7.6 (-)
unnamed: C34.1, R52.2, U7.10 (+)
unnamed: R56.2, R57.1, U7.9 (-)
unnamed: C32.2, FIL3.1, R57.2, U7.8, U7.12 (+)
unnamed: R58.2, R59.1, U7.13 (-)
unnamed: R25.1, R27.1, U9.2 (-)
unnamed: C22.1, R24.2, U9.5 (+)
unnamed: R30.2, R31.1, U9.6 (-)
unnamed: C20.2, FIL1.1, R31.2, U9.7, U9.10 (+)
unnamed: R28.2, R29.1, U9.9 (-)
unnamed: RAW1.1, U9.3 (+), U10.10 (VO), U10.11 (SENSE)
unnamed: R21.2, U10.2 (~SLEEP)
unnamed: RAW2.1, U11.3 (+), U12.10 (VO), U12.11 (SENSE)
unnamed: R39.1, R41.1, U11.2 (-)
unnamed: C28.1, R38.2, U11.5 (+)
unnamed: R44.2, R45.1, U11.6 (-)
unnamed: C26.2, FIL2.1, R45.2, U11.7, U11.10 (+)
unnamed: R42.2, R43.1, U11.9 (-)
unnamed: R35.2, U12.2 (~SLEEP)
unnamed: RAW3.1, U7.5 (+), U13.10 (VO), U13.11 (SENSE)
unnamed: R49.2, U13.2 (~SLEEP)

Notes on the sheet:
Channel Two
Channel Three
Channel One

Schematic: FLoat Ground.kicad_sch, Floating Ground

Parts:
C14, C15: 100uF; CP_Elec_3x5.4
R17, R18, R19, R20: 10k; R_0603_1608Metric_Pad0.98x0.95mm_HandSolder
U7: LM324A; SOIC127P600X175-14N

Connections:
12V: C14.1, R17.1, R18.1; also elsewhere on the board
Float GND: C14.2, C15.1, R18.2, R19.1; also elsewhere on the board
Float GND 2: U7.1, U7.2 (-); also elsewhere on the board
GND: C15.2, R19.2, R20.2; also elsewhere on the board
unnamed: R17.2, R20.1, U7.3 (+)

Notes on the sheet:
V Clamp and Floating Ground

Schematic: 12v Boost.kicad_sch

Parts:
C12: 1u; C_0402_1005Metric
C13: 1u; C_0603_1608Metric
D5: 1N5819; D_SOD-123
L1: 10uH; L_Cenker_CKCS3012; MPN FXL0420-100-M
R15: 48.7K; R_0402_1005Metric
R16: 5.6K; R_0402_1005Metric
U6: AP3012; SOT-23-5

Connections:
3.3V: C12.1, L1.1, U6.4 (~SHDN), U6.5 (IN); also elsewhere on the board
12V: C13.1, D5.1 (K), R15.1; also elsewhere on the board
GND: C12.2, C13.2, R16.2, U6.2 (GND); also elsewhere on the board
unnamed: D5.2 (A), L1.2, U6.1 (SW)
unnamed: R15.2, R16.1, U6.3 (FB)

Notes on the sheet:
3V3 to 12V

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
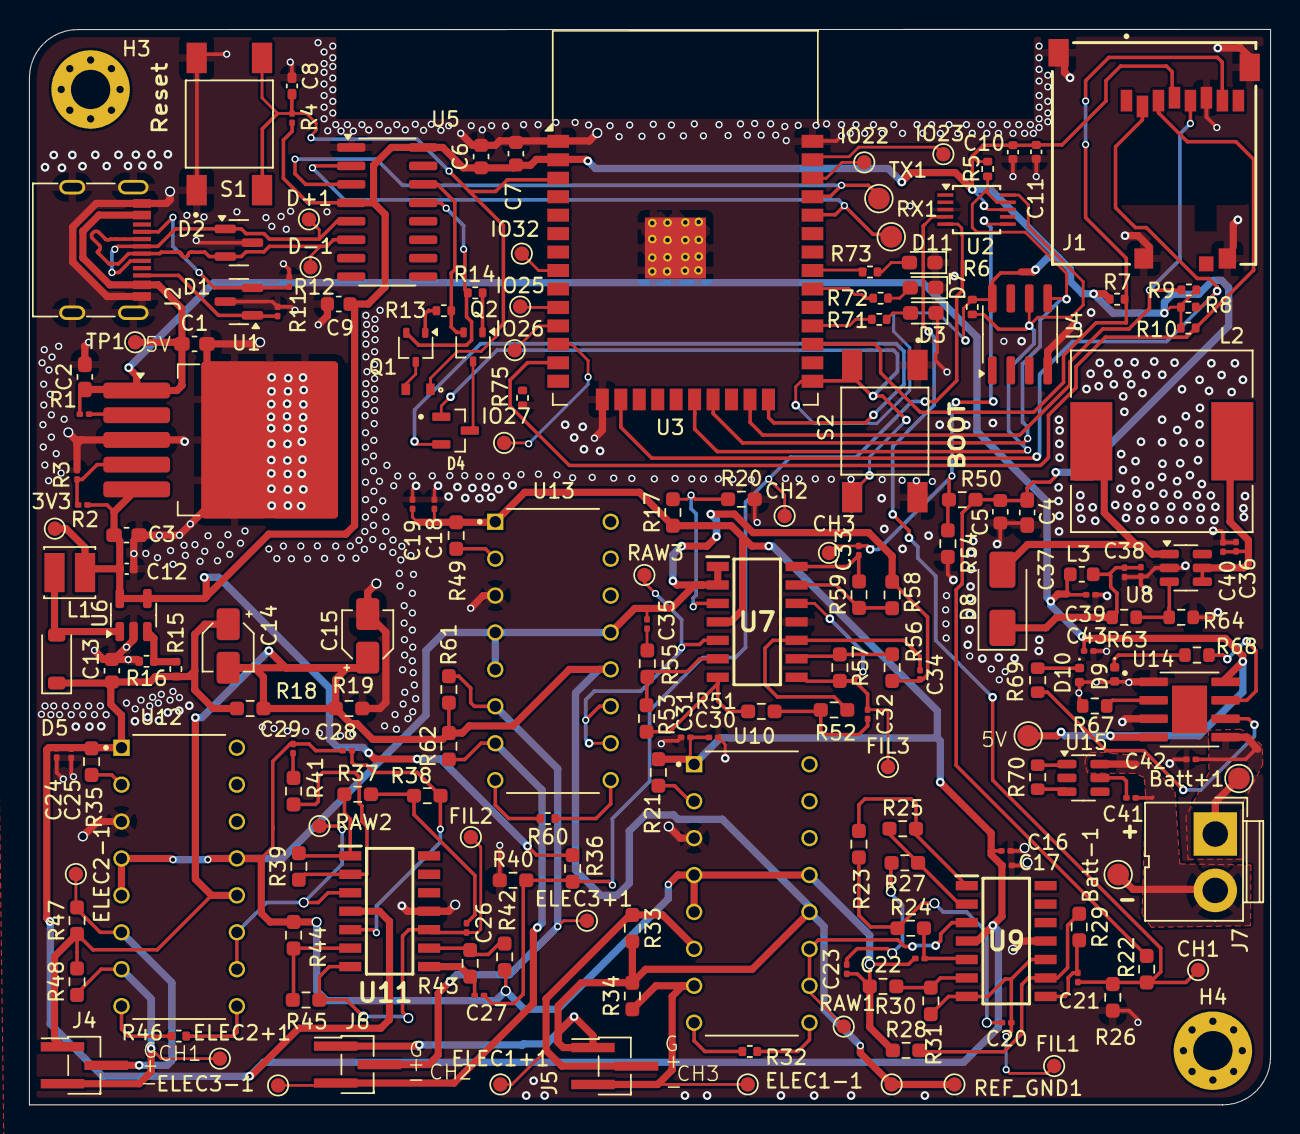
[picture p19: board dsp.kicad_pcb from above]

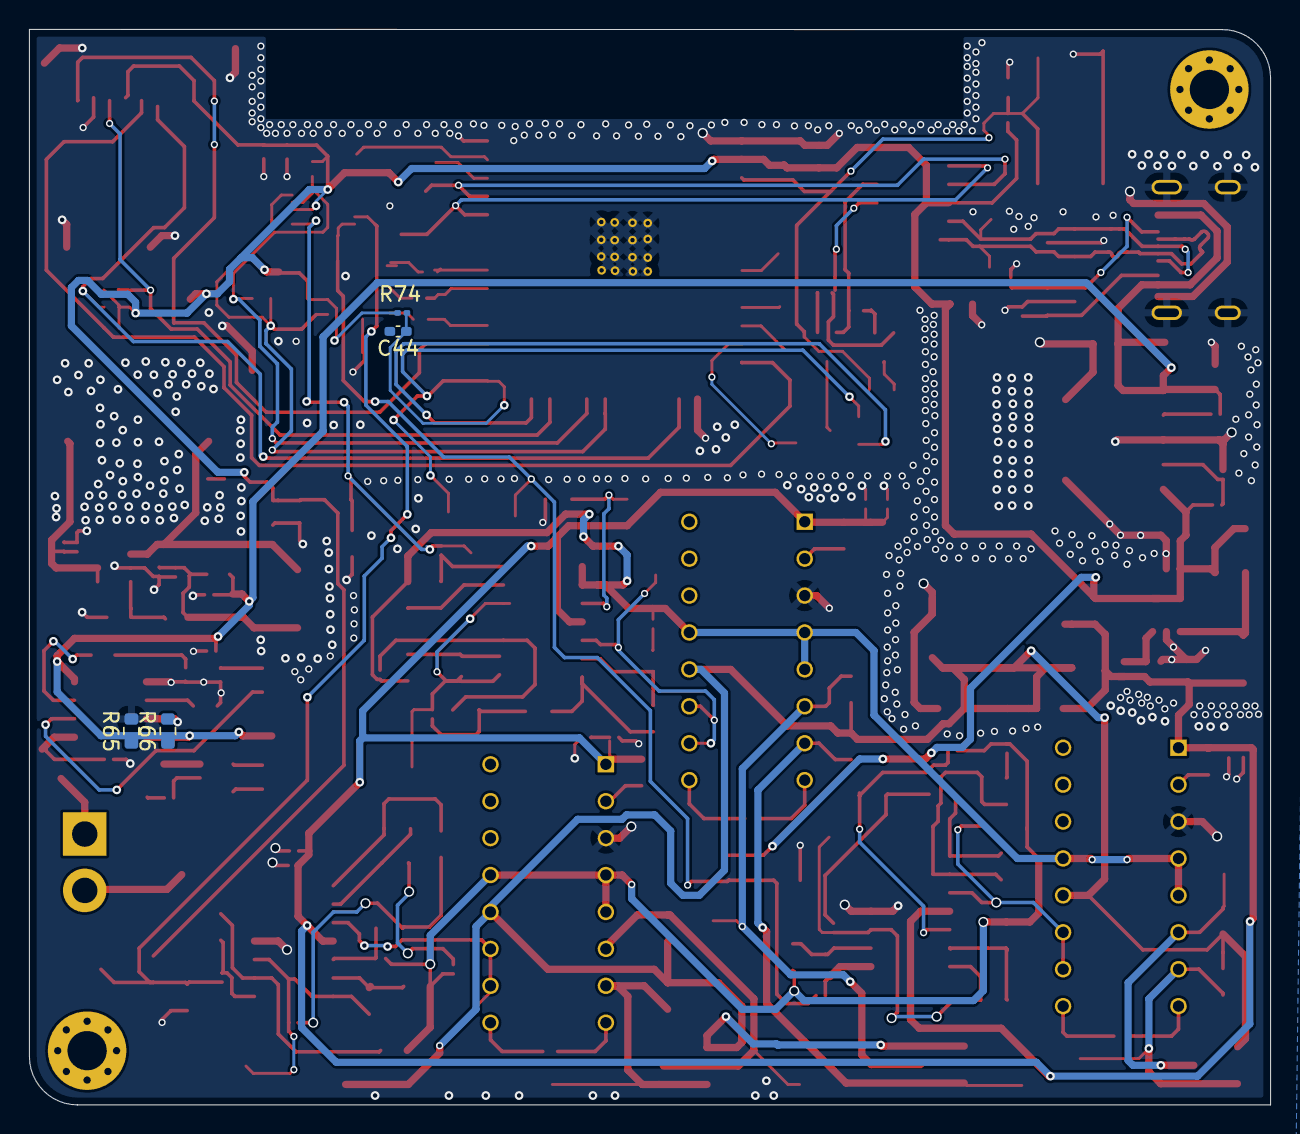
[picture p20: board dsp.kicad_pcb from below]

Board: 2 copper layers, 85.4 x 74.0 mm, 192 parts (4 on the bottom side), 107 nets.

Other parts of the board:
IO22: 22; TestPoint_Pad_D1.0mm
